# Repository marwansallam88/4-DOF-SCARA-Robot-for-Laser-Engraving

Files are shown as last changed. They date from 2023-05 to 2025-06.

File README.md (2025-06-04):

# 4-DOF SCARA Robot for Laser Engraving
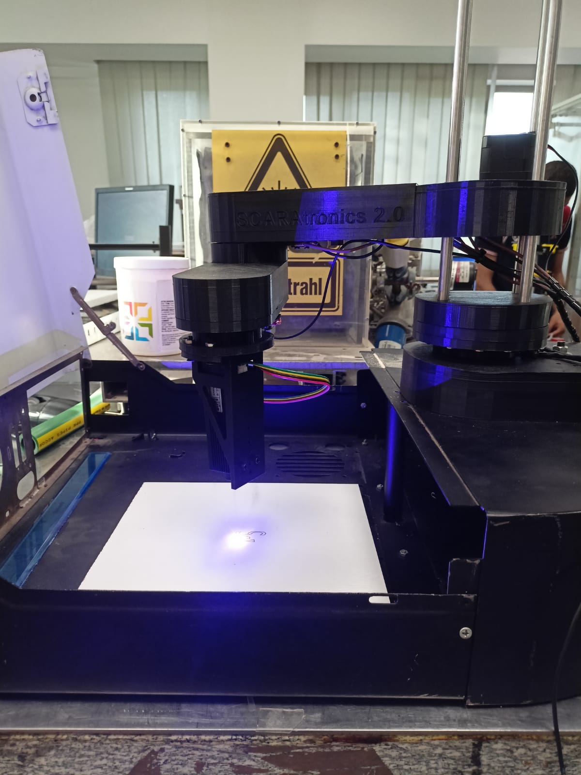
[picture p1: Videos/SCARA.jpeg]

## Overview
This repository contains the design, control, and simulation files for a 4-DOF SCARA robot used for laser engraving. The project includes:
- **Mathematical modeling** (kinematics and dynamics) using MATLAB/Simulink.
- **Control algorithms** implemented via Marlin firmware on an Arduino Mega.
- **3D design files** (SolidWorks) for robot assembly.
- **Experimental results** showcasing laser engraving capabilities.

## Features
- **4 Degrees of Freedom**: Three rotational joints (X-Y plane) and one vertical prismatic joint (Z-axis).
- **Laser Engraving**: Custom end-effector for precise engraving on workpieces.
- **Inverse Kinematics**: Geometric and algebraic solutions for path planning.
- **Open-Source Control**: Marlin firmware configured for SCARA kinematics.
- **Modular Design**: Easily replaceable end-effectors for diverse applications.

## Repository Structure
SCARA-Robot-Laser-Engraving/  
├── SCARA MODEL/ # 3D models and assembly files  
├── Mathmetical Model/ # Forward/inverse kinematics and dynamics  
├── Control/Marlin-2.0.x/ # Marlin configuration and motor test codes  
├── Videos/ # Images and data from engraving tests  
└── Thesis/ # Thesis PDF and supplementary notes  

## Key Components
- **Hardware**:
  - NEMA 17 stepper motors (4x).
  - GT2 belts and pulleys for joint actuation.
  - 12V laser module (PWM-controlled).
  - Limit switches for homing.
- **Software**:
  - MATLAB/Simulink for simulation.
  - Marlin firmware (customized for SCARA).
  - Repetier-Host for G-code execution.
  - Inkscape + LaserTools plugin for G-code generation.

## Setup Instructions
1. **Assembly**:
   - 3D-print parts from `SCARA MODEL`.
   - Assemble belts, pulleys, and motors as per the thesis (Chapter 5).
2. **Electronics**:
   - Connect steppers, limit switches, and laser to Arduino Mega/RAMPS 1.6.
   - Adjust stepper driver currents using `V_ref = I_mot * 8 * R_sense`.
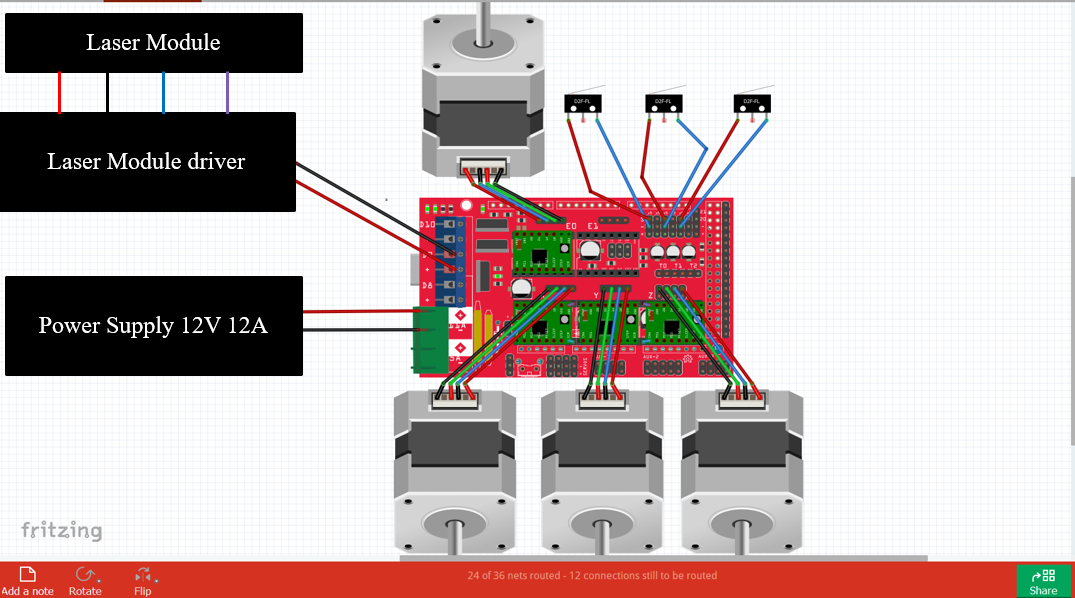
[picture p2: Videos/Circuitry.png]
     
3. **Firmware**:
   - Upload Marlin firmware (`Control/Marlin-2.0.x`) with SCARA-specific settings:
     - Arm lengths: 228mm (Link 1), 136.5mm (Link 2).
     - Steps/unit: 90 (Joint 1), 29.206 (Joint 2), 400 (Z-axis).
4. **Calibration**:
   - Home the robot using limit switches.
   - Focus the laser at ~5cm height (adjust lens rotation).
5. **Operation**:
   - Generate G-code in Inkscape (vector paths → LaserTools plugin).
   - Execute via Repetier-Host.

## Results
- **Simulations**: Validated forward/inverse kinematics and dynamics (see `Mathmetical Model/`).
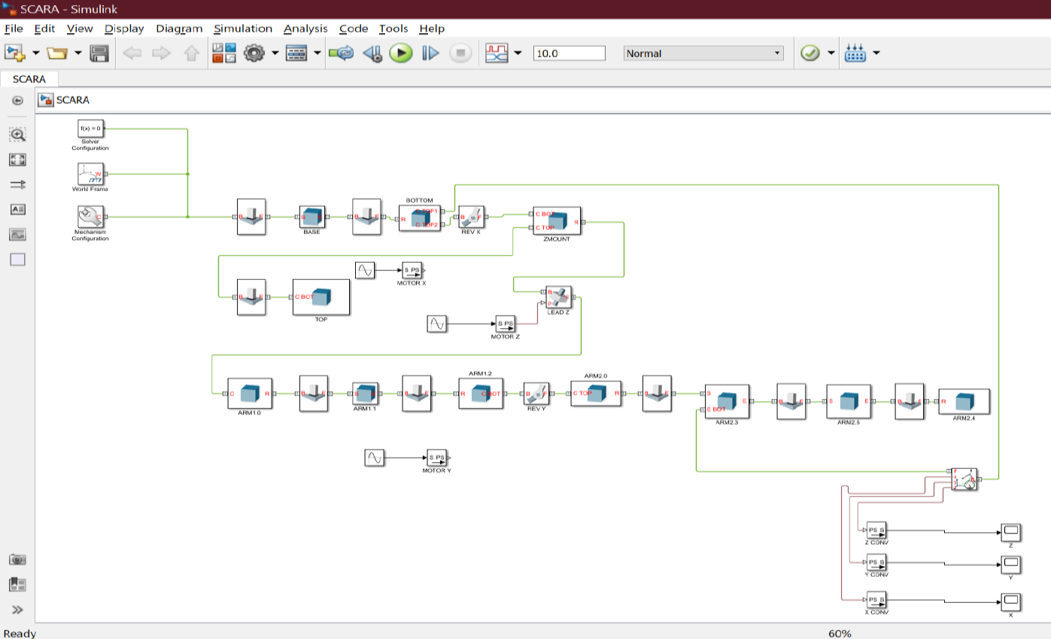
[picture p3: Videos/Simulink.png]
  
- **Engraving Tests**:
  - Contour shapes (e.g., squares, logos).
  - Text engraving (e.g., "GUC 20 YEARS").
  - Infill patterns (e.g., bat shape).
  <p align="center">
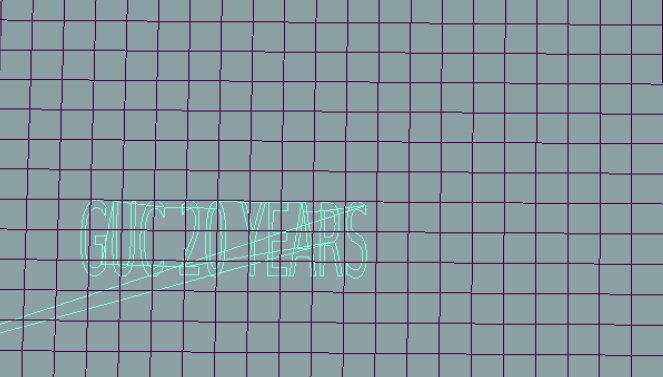
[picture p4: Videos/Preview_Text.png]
  
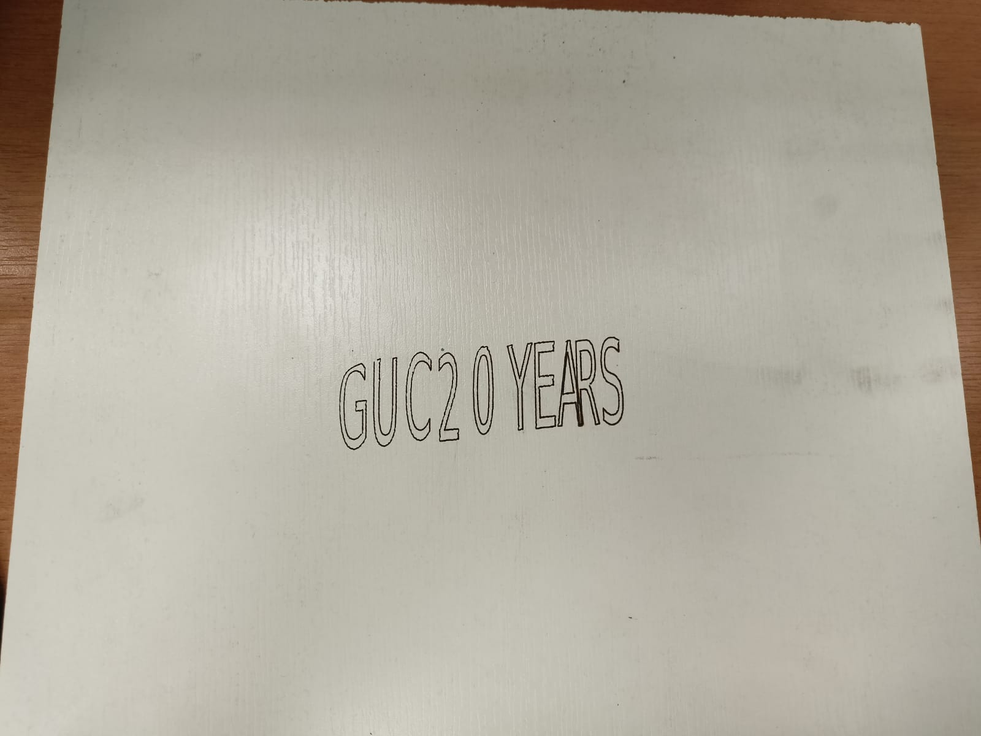
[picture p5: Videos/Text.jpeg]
  
</p>

## Future Work
- Integrate computer vision for real-time adjustments.
- Implement soft grippers for pick-and-place tasks.
- Enhance rigidity to reduce positional errors.

## References
- Thesis: *Four Degrees of Freedom SCARA Robot Used for Laser Engraving* (Marwan Sallam, 2022).
- [Marlin Firmware](https://marlinfw.org/)
- [Inkscape LaserTools](https://github.com/jncordon/lasertools)

## License
Open-source (MIT). Use freely for academic or personal projects.

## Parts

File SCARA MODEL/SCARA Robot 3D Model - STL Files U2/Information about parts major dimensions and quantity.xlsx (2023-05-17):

Part Name | Quantity | Length(mm) | Width(mm) | Height(mm) | Extra Info |  | Colour
Arduino Mega Case | 1 | 120 | 85 | 45 |  |  | Black
Arduino Mega Case p2 | 1 | 120 | 80 | 40 |  |  | Black
Arm 1 | 1 | 205 | 80 | 45 | Will carrry heavy load so should be strong but lightweight |  | Black
Arm 1 Cover | 1 | 205 | 80 | 5 | Will carrry heavy load so should be strong but lightweight |  | Black
Base | 1 | 215 | 140 | 45 | This is the base of porject so should be dense |  | Black
Base Cover | 1 | 120 | 120 | 25 | This is the base of porject so should be dense |  | Black
Arm 2 | 1 | 225 | 80 | 35 | Will carrry heavy load so should be strong but lightweight |  | Black
Arm 2 cover | 1 | 225 | 80 | 10 | Will carrry heavy load so should be strong but lightweight |  | Black
Arm 1 motor pulley - 63 Teeth - D40mm | 1 | 40 | 40 | 15 | Should withstand friction and force |  | Black
Arm 1 Pulley Middle - 44 Teeth - 99 Teeth - D31mm - D66mm | 1 | 66 | 66 | 20 | Should withstand friction and force |  | Black
Arm 2 Motor Pulley - 68 Teeth - D46mm | 1 | 46 | 46 | 15 | Should withstand friction and force |  | Black
Base Motor Pulley - 20 Teeth - D14.5mm | 1 | 14.5 | 14.5 | 15 | Should withstand friction and force |  | Black
Base Pulley - 44 Teeth - 81 Teeth - D31mm - D52mm | 1 | 52 | 52 | 20 | Should withstand friction and force |  | Black
Tensioner Pulley | 5 | 15 | 15 | 15 | Should withstand friction and force |  | Black
GT2 Pulley -110 teeth- J1 | 1 | 72 | 72 | 25 | Should withstand friction and force |  | Black
GT2 Pulley -92 teeth- J2 | 1 | 60.5 | 60.5 | 20 | Should withstand friction and force |  | Black
GT2 Pulley -90 teeth- J3 | 1 | 59 | 59 | 25 | Should withstand friction and force |  | Black
Smooth rod clamp | 8 | 40 | 15 | 30 |  |  | Black
Z-axis top plate | 1 | 120 | 120 | 25 |  |  | Black
Z-axis Mount Platform | 1 | 125 | 120 | 45 |  |  | Black
Z-axis Bottom Plate | 1 | 120 | 120 | 10 |  |  | Black
Top cover | 1 | 120 | 120 | 25 |  |  | Black
J3 Coupler | 1 | 80 | 80 | 25 |  |  | Black
J2 Coupler | 1 | 80 | 80 | 25 |  |  | Black
J1 Coupler | 1 | 120 | 120 | 30 |  |  | Black
Laser Module Holder | 1 | 80 | 45 | 115 |  |  | Black
 | New |  |  |  | Old
using teeth | Reduction Ratio
First Joint | 10.125 | 10.125 | 90.00000000 |  | 20 | 177.7777778
Second Joint | 3.285714286 | 3.286 | 29.20634921 |  | 16 | 142.2222222
Third Joint | 1.323529412 | 1.324 | 11.76470588 |  | 4.5 | 40
 |  |  |  |  |  |  | 0
using diameters
First Joint | 9.999524881 | 10 | 88.88466561
Second Joint | 3.573844215 | 3.574 | 31.76750413
Third Joint | 1.328528779 | 1.329 | 11.80914470

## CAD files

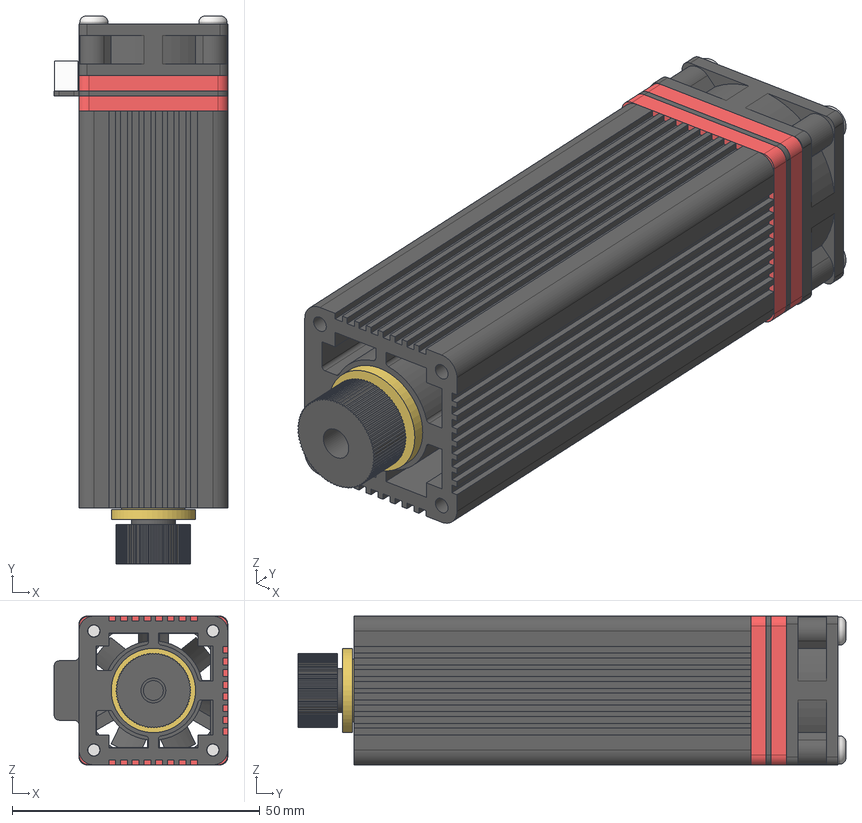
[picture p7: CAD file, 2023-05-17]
SCARA MODEL/SCARA Robot 3D Model - STL Files U2/neje-n30820-laser-module-20w-1.snapshot.1/A-NEJE_N30820_assembled.stp
35.0 x 110.5 x 30.0 mm
NEJE_N30820_Aluminiumbody
NEJE_N30820_Lens
NEJE_N30820_SLA-Spacer(red) x 2
NEJE_N30820_PCB
ANSI B18.3.4M - M3 x 0.5 x 30 x 4

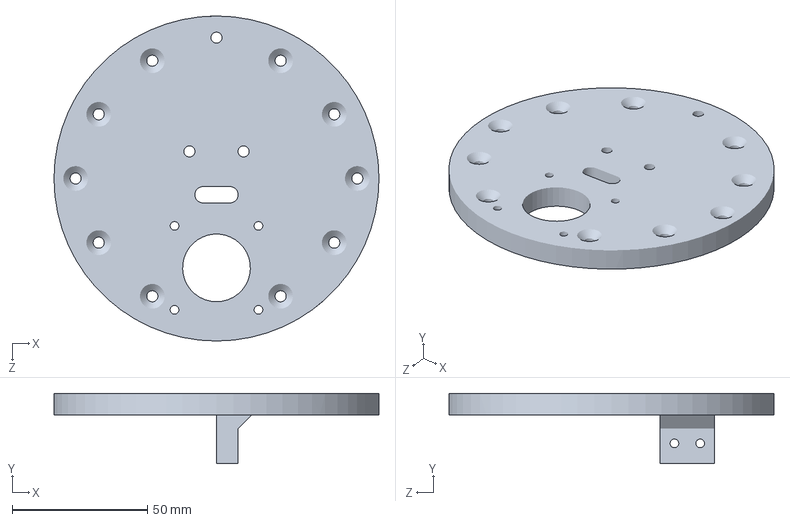
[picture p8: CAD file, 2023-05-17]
SCARA MODEL/SCARA Robot 3D Model - STL Files U2/Z-axis Top Plate.SLDPRT
120.0 x 26.0 x 120.0 mm

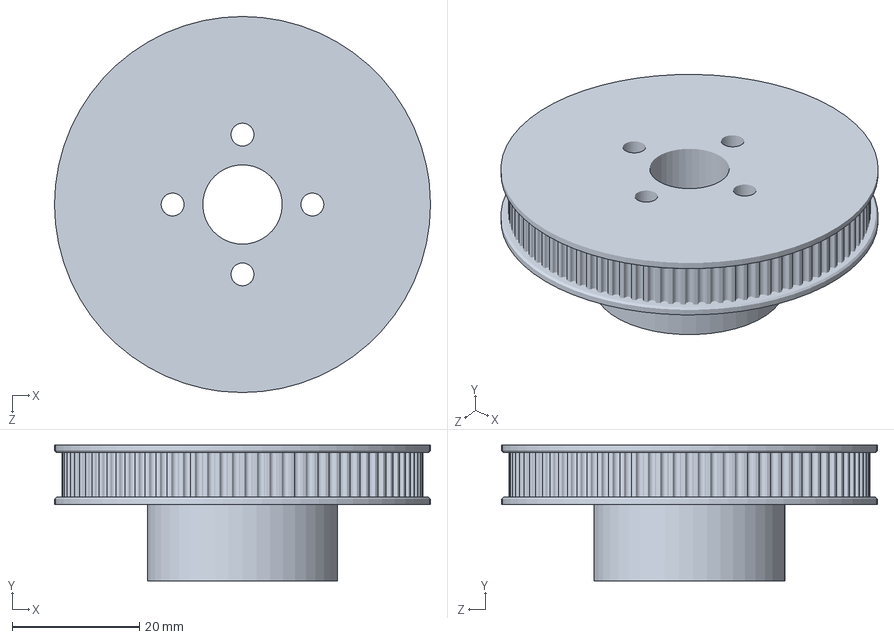
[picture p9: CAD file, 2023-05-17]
SCARA MODEL/SCARA Robot 3D Model - STL Files U2/GT2 Pulley - 90 teeth - J3 - D59mm.SLDPRT
59.2 x 21.4 x 59.2 mm

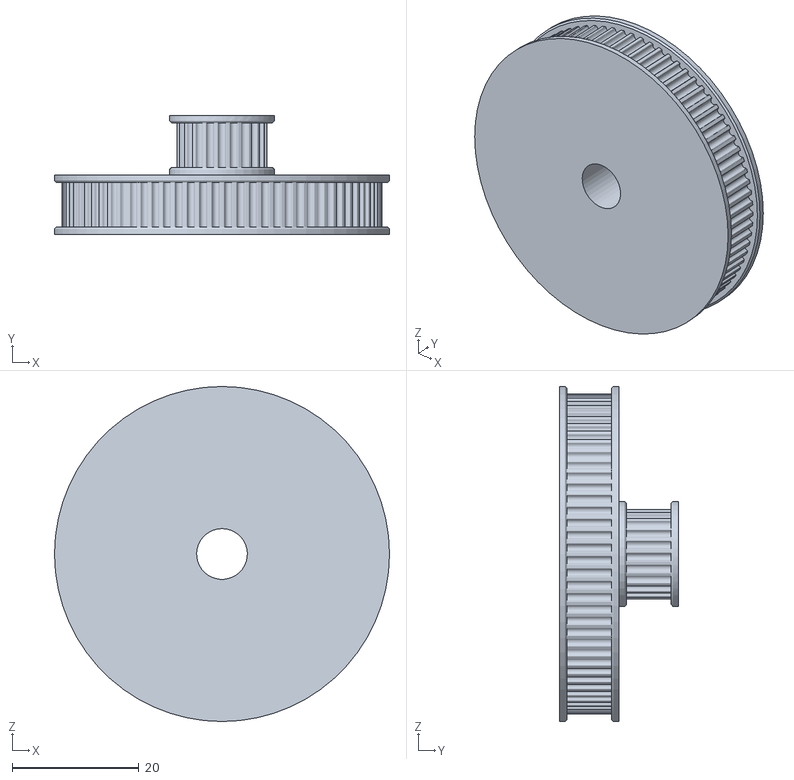
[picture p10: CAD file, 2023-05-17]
SCARA MODEL/SCARA Robot 3D Model - STL Files U2/GT2 Pulley - 23 - 80 teeth.STL
52.8 x 18.8 x 52.8

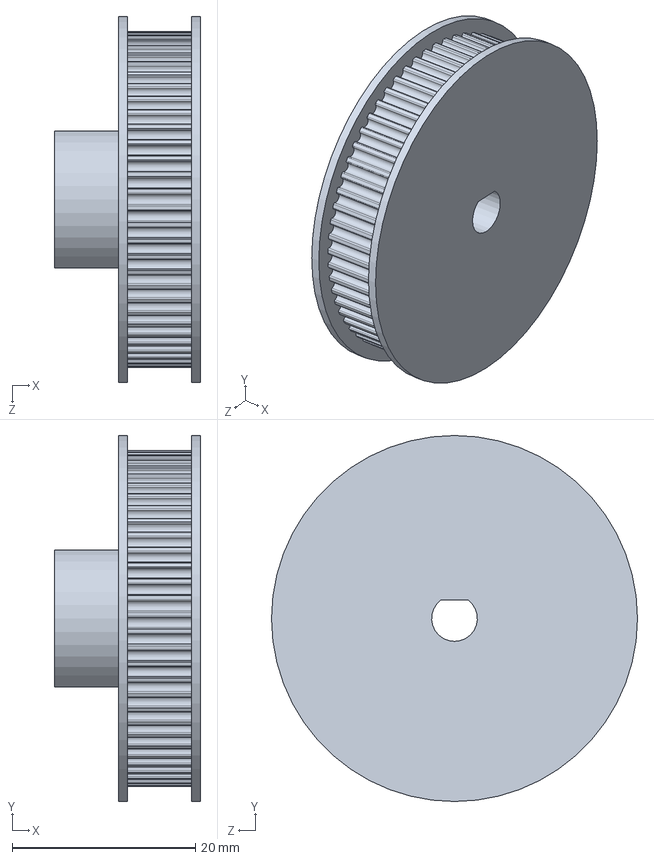
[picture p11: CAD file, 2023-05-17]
SCARA MODEL/SCARA Robot 3D Model - STL Files U2/Arm 1 motor pulley - 63 Teeth - D40mm.SLDPRT
16.0 x 40.0 x 40.0 mm

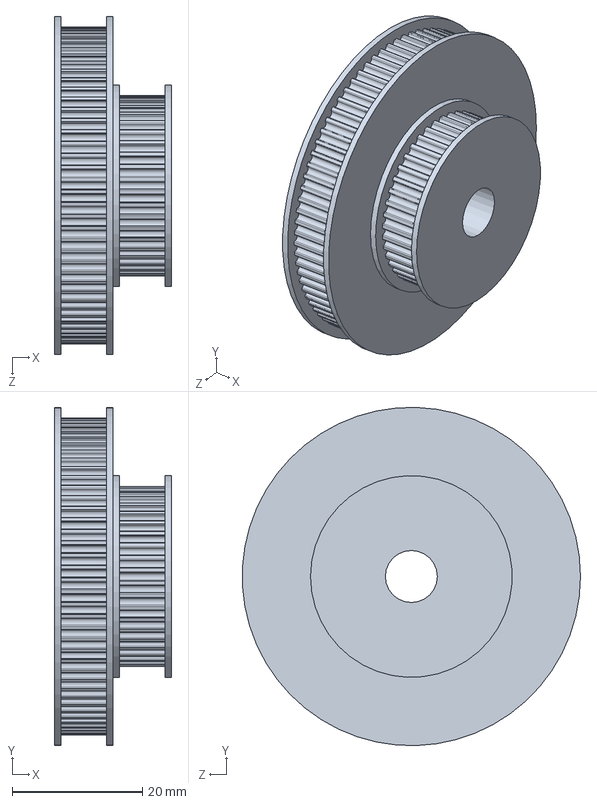
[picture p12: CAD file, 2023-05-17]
SCARA MODEL/SCARA Robot 3D Model - STL Files U2/Base Pulley - 44 Teeth - 81 Teeth - D31mm - D52mm.SLDPRT
18.0 x 52.0 x 52.0 mm

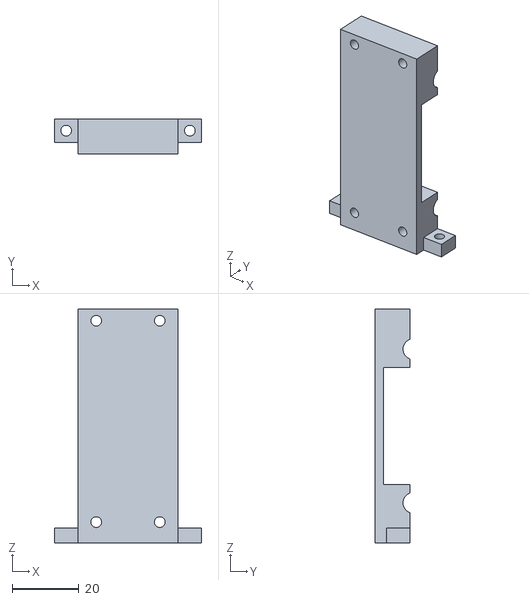
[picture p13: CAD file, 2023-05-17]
SCARA MODEL/SCARA Robot 3D Model - STL Files U2/Gripper Cover.STL
44.0 x 10.5 x 70.0

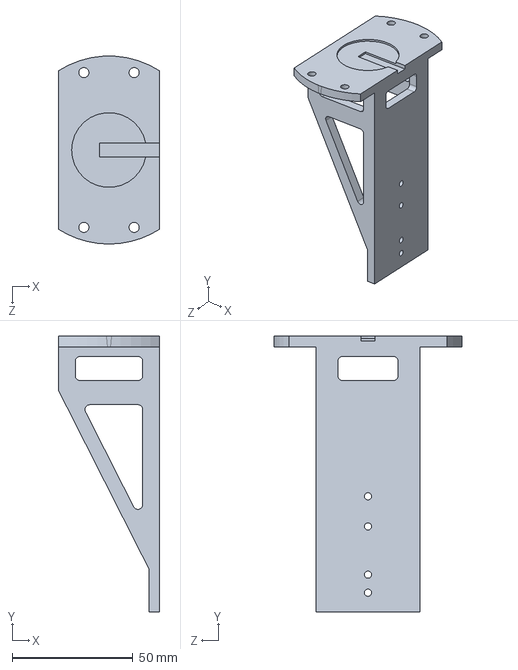
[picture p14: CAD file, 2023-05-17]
SCARA MODEL/SCARA Robot 3D Model - STL Files U2/Laser module holder.SLDPRT
42.0 x 114.5 x 78.0 mm

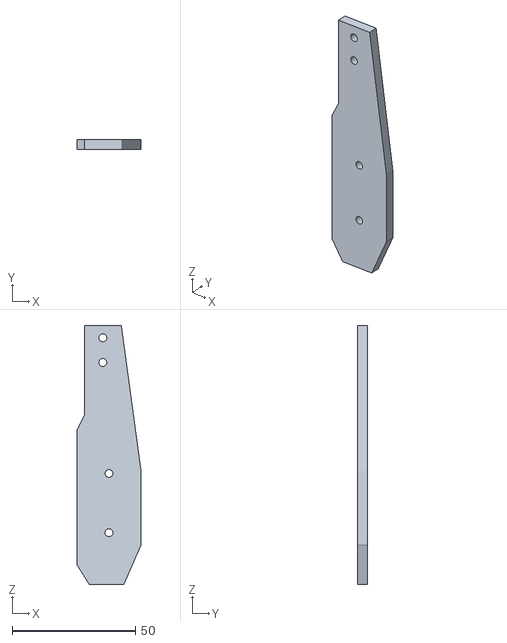
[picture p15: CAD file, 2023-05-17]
SCARA MODEL/SCARA Robot 3D Model - STL Files U2/Gripper Hand Right.STL
26.0 x 4.00 x 105.0

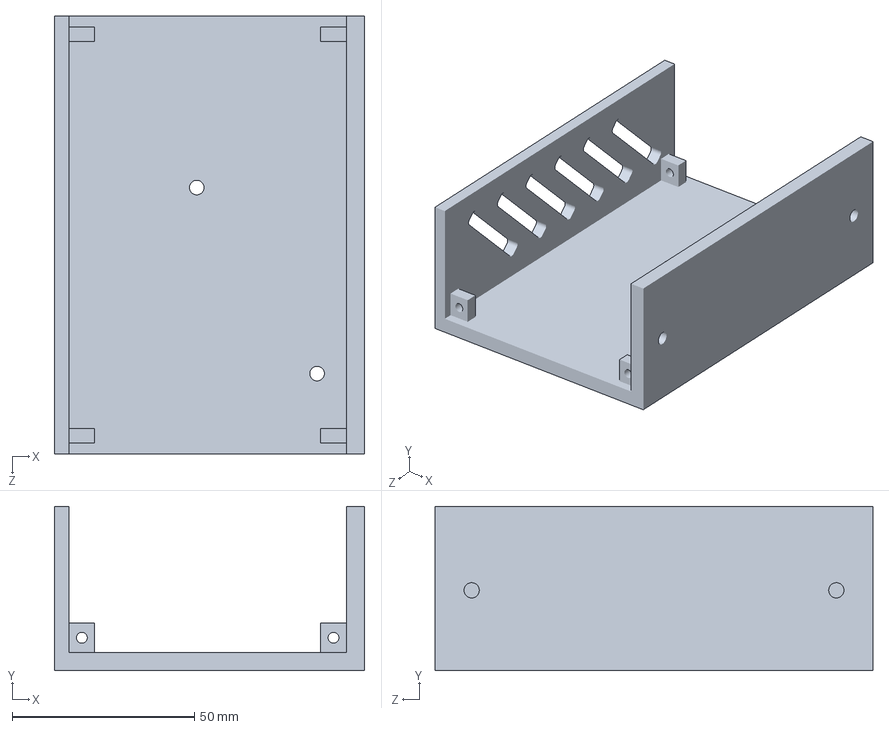
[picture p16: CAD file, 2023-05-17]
SCARA MODEL/SCARA Robot 3D Model - STL Files U2/Arduino Mega case.SLDPRT
85.0 x 45.0 x 120.0 mm

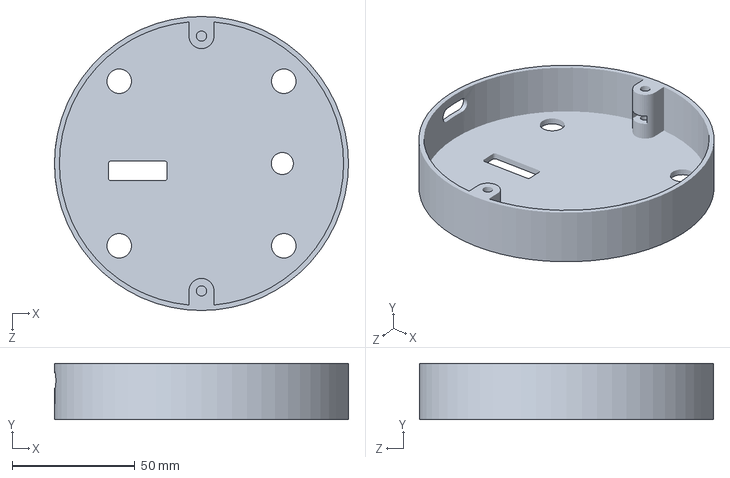
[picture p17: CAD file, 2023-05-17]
SCARA MODEL/SCARA Robot 3D Model - STL Files U2/Top cover.SLDPRT
120.0 x 23.0 x 120.0 mm

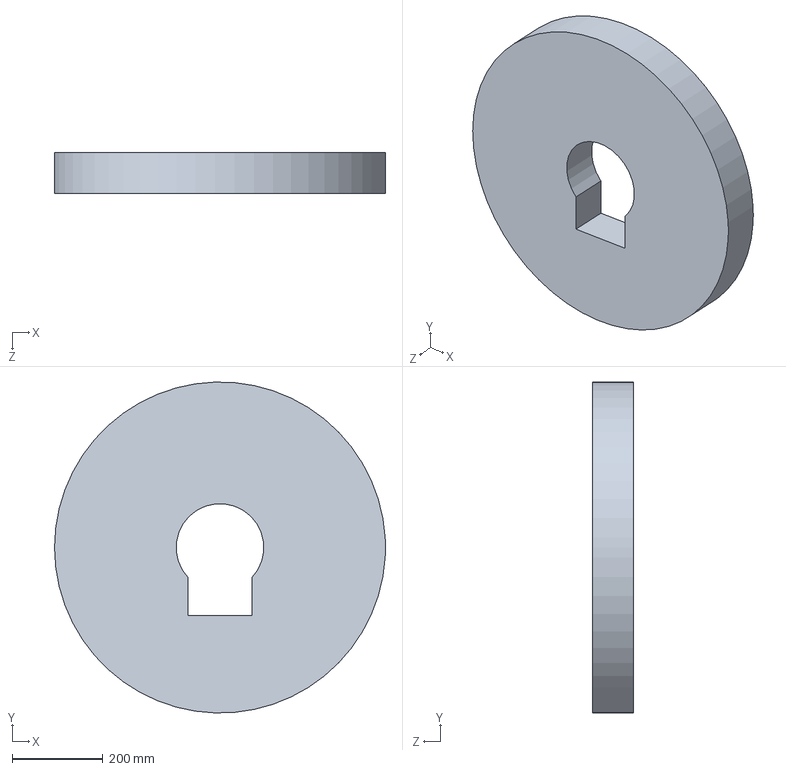
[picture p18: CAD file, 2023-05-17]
SCARA MODEL/SCARA Robot 3D Model - STL Files U2/workspace.SLDPRT
729.0 x 728.7 x 91.0 mm

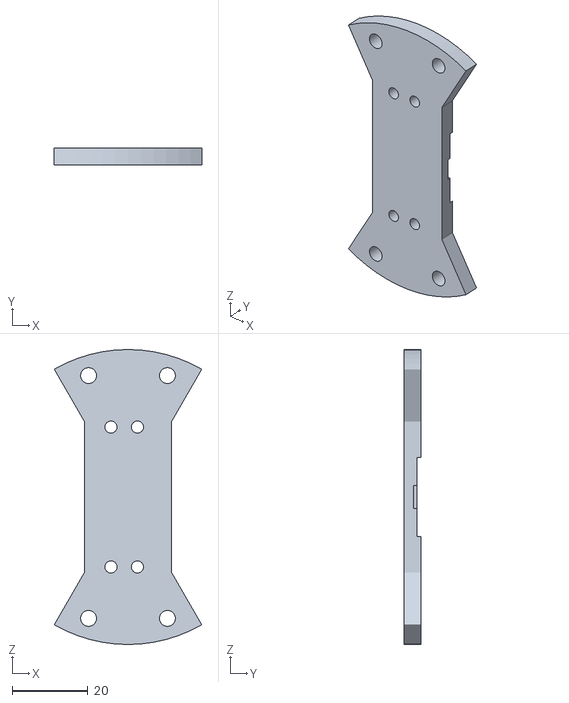
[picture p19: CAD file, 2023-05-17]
SCARA MODEL/SCARA Robot 3D Model - STL Files U2/Gripper to J3 connector.STL
39.0 x 4.50 x 78.0

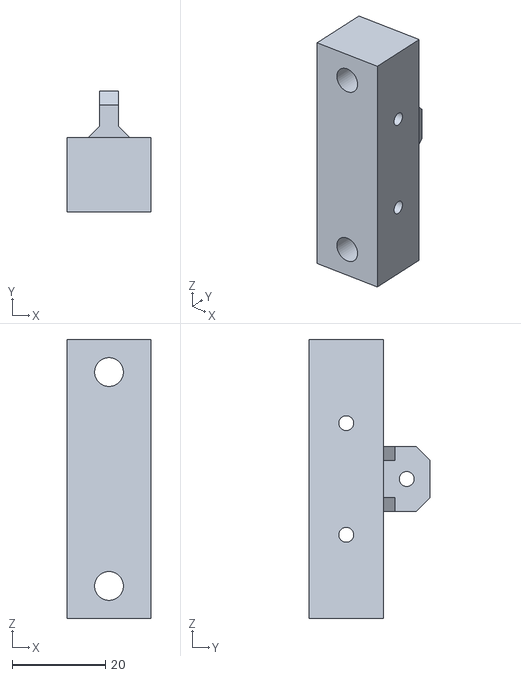
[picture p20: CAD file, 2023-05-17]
SCARA MODEL/SCARA Robot 3D Model - STL Files U2/Gripper Mechanism Slider.STL
18.0 x 26.0 x 60.0

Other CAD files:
SCARA MODEL/SCARA Robot 3D Model - STL Files U2/SCARA OFFSET.SLDPRT
SCARA MODEL/SCARA Robot 3D Model - STL Files U2/J3 Coupler.SLDPRT
SCARA MODEL/SCARA Robot 3D Model - STL Files U2/Smooth Rod Clamp.SLDPRT
SCARA MODEL/SCARA Robot 3D Model - STL Files U2/GT2 Pulley - 110 teeth - J1.STL
SCARA MODEL/SCARA Robot 3D Model - STL Files U2/Arduino Mega case p2.SLDPRT
SCARA MODEL/SCARA Robot 3D Model - STL Files U2/Arduino Mega case p2.STL
SCARA MODEL/SCARA Robot 3D Model - STL Files U2/Arduino Mega case.STL
SCARA MODEL/SCARA Robot 3D Model - STL Files U2/Arduino UNO case p1.STL
SCARA MODEL/SCARA Robot 3D Model - STL Files U2/Arduino UNO case p2.STL
SCARA MODEL/SCARA Robot 3D Model - STL Files U2/Arm 1 Cover.SLDPRT
SCARA MODEL/SCARA Robot 3D Model - STL Files U2/Arm 1 Cover.STL
SCARA MODEL/SCARA Robot 3D Model - STL Files U2/Arm 1 Pulley Middle - 44 Teeth - 99 Teeth - D31mm - D66mm.SLDPRT
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

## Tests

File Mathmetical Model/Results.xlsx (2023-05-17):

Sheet: Kine S Y
Time | Y
0 | 0
0.000430977095 | 5.4086534e-06
0.0008619541901 | 3.539515969e-05
0.001358518811 | 0.0001111131155
0.001981448586 | 0.000265702842
0.002742152024 | 0.0005248783451
0.003680813786 | 0.0009137942667
0.004877582879 | 0.001467886721
0.006560880035 | 0.002291062328
0.009042260391 | 0.003528914422
0.01148760951 | 0.004753101366
0.01454943029 | 0.006286573817
0.01791619063 | 0.007972568813
0.02113159993 | 0.009582567961
0.02416520633 | 0.01110131924
0.02737275602 | 0.0127067233
0.0314853292 | 0.01476467813
0.03372316461 | 0.01588369875
0.03596100003 | 0.01700259135
0.03910755649 | 0.0185754654
0.04258274593 | 0.02031205186
0.0455207786 | 0.0217792712
0.04799304481 | 0.023013124
0.05060936536 | 0.02431852073
0.05368082652 | 0.02585037017
0.05682579027 | 0.02741802755
0.05964560509 | 0.02882260458
0.06226516506 | 0.03012662994
0.06503041043 | 0.0315024629
0.06800560244 | 0.03298185339
0.07093906743 | 0.03443944841
0.07369502907 | 0.03580778309
0.07640166269 | 0.03715067099
0.07921018647 | 0.03854312285
0.08208178451 | 0.03996573548
0.08489327589 | 0.04135739015
0.08763067439 | 0.04271120838
0.09037467029 | 0.04406714455
0.09316348712 | 0.04544402519
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

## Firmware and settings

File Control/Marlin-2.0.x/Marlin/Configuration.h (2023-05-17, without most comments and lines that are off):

#pragma once
#define CONFIG_EXAMPLES_DIR "SCARA/MP_SCARA"
#define CONFIGURATION_H_VERSION 02000900
#define MP_SCARA
  #define SCARA_SEGMENTS_PER_SECOND 100
  #define SCARA_LINKAGE_1  228    // (mm)
  #define SCARA_LINKAGE_2 136.5    // (mm)
  #define SCARA_OFFSET_X    240       // (mm)
  #define SCARA_OFFSET_Y    -80       // (mm)
    #define SCARA_OFFSET_THETA1  0 // degrees
    #define SCARA_OFFSET_THETA2 0 // degrees
#define STRING_CONFIG_H_AUTHOR "(none, default config)" // Who made the changes.
#define SHOW_BOOTSCREEN
#define SERIAL_PORT 0
#define BAUDRATE 115200
  #define MOTHERBOARD BOARD_RAMPS_14_EFB
#define CUSTOM_MACHINE_NAME "SCARA"
#if LINEAR_AXES >= 4
  #define AXIS4_NAME 'A' // :['A', 'B', 'C', 'U', 'V', 'W']
#endif
#if LINEAR_AXES >= 5
  #define AXIS5_NAME 'B' // :['A', 'B', 'C', 'U', 'V', 'W']
#endif
#if LINEAR_AXES >= 6
  #define AXIS6_NAME 'C' // :['A', 'B', 'C', 'U', 'V', 'W']
#endif
#define EXTRUDERS 1
#define DEFAULT_NOMINAL_FILAMENT_DIA 1.75
#define TEMP_SENSOR_0 1
#define TEMP_SENSOR_1 0
#define TEMP_SENSOR_2 0
#define TEMP_SENSOR_3 0
#define TEMP_SENSOR_4 0
#define TEMP_SENSOR_5 0
#define TEMP_SENSOR_6 0
#define TEMP_SENSOR_7 0
#define TEMP_SENSOR_BED 1
#define TEMP_SENSOR_PROBE 0
#define TEMP_SENSOR_CHAMBER 0
#define TEMP_SENSOR_COOLER 0
#define TEMP_SENSOR_REDUNDANT 0
#define DUMMY_THERMISTOR_998_VALUE  25
#define DUMMY_THERMISTOR_999_VALUE 100
#define TEMP_RESIDENCY_TIME          3  // (seconds) Time to wait for hotend to "settle" in M109
#define TEMP_HYSTERESIS              2  // (°C) Temperature proximity considered "close enough" to the target
#define TEMP_WINDOW                  1  // (°C) Temperature proximity for the "temperature reached" timer
#define TEMP_BED_RESIDENCY_TIME      0  // (seconds) Time to wait for bed to "settle" in M190
#define TEMP_BED_WINDOW              1  // (°C) Temperature proximity for the "temperature reached" timer
#define TEMP_BED_HYSTERESIS          3  // (°C) Temperature proximity considered "close enough" to the target
#define TEMP_CHAMBER_RESIDENCY_TIME 10  // (seconds) Time to wait for chamber to "settle" in M191
#define TEMP_CHAMBER_WINDOW          1  // (°C) Temperature proximity for the "temperature reached" timer
#define TEMP_CHAMBER_HYSTERESIS      3  // (°C) Temperature proximity considered "close enough" to the target
#if TEMP_SENSOR_REDUNDANT
  #define TEMP_SENSOR_REDUNDANT_SOURCE     1  // The sensor that will provide the redundant reading.
  #define TEMP_SENSOR_REDUNDANT_TARGET     0  // The sensor that we are providing a redundant reading for.
  #define TEMP_SENSOR_REDUNDANT_MAX_DIFF  10  // (°C) Temperature difference that will trigger a print abort.
#endif
#define HEATER_0_MINTEMP   5
#define HEATER_1_MINTEMP   5
#define HEATER_2_MINTEMP   5
#define HEATER_3_MINTEMP   5
#define HEATER_4_MINTEMP   5
#define HEATER_5_MINTEMP   5
#define HEATER_6_MINTEMP   5
#define HEATER_7_MINTEMP   5
#define BED_MINTEMP        5
#define CHAMBER_MINTEMP    5
#define HEATER_0_MAXTEMP 275
#define HEATER_1_MAXTEMP 275
#define HEATER_2_MAXTEMP 275
#define HEATER_3_MAXTEMP 275
#define HEATER_4_MAXTEMP 275
#define HEATER_5_MAXTEMP 275
#define HEATER_6_MAXTEMP 275
#define HEATER_7_MAXTEMP 275
#define BED_MAXTEMP      150
#define CHAMBER_MAXTEMP  60
#define HOTEND_OVERSHOOT 15   // (°C) Forbid temperatures over MAXTEMP - OVERSHOOT
#define BED_OVERSHOOT    10   // (°C) Forbid temperatures over MAXTEMP - OVERSHOOT
#define COOLER_OVERSHOOT  2   // (°C) Forbid temperatures closer than OVERSHOOT
#define PIDTEMP
#define BANG_MAX 255     // Limits current to nozzle while in bang-bang mode; 255=full current
#define PID_MAX BANG_MAX // Limits current to nozzle while PID is active (see PID_FUNCTIONAL_RANGE below); 255=full current
#define PID_K1 0.95      // Smoothing factor within any PID loop
    #define DEFAULT_Kp  24.50
    #define DEFAULT_Ki   1.72
    #define DEFAULT_Kd  87.73
#define PIDTEMPBED
#define MAX_BED_POWER 255 // limits duty cycle to bed; 255=full current
  #define DEFAULT_bedKp 630.14
  #define DEFAULT_bedKi 121.71
  #define DEFAULT_bedKd 815.64
#define MAX_CHAMBER_POWER 255 // limits duty cycle to chamber heater; 255=full current
  #define PID_FUNCTIONAL_RANGE 20 // If the temperature difference between the target temperature and the actual temperature
#define PREVENT_COLD_EXTRUSION
#define EXTRUDE_MINTEMP 170
#define PREVENT_LENGTHY_EXTRUDE
#define EXTRUDE_MAXLENGTH 200
#define THERMAL_PROTECTION_HOTENDS // Enable thermal protection for all extruders
#define THERMAL_PROTECTION_BED     // Enable thermal protection for the heated bed
#define THERMAL_PROTECTION_CHAMBER // Enable thermal protection for the heated chamber
#define THERMAL_PROTECTION_COOLER  // Enable thermal protection for the laser cooling
#define USE_XMIN_PLUG
#define USE_YMIN_PLUG
#define USE_ZMIN_PLUG
#define ENDSTOPPULLUPS
#define X_MIN_ENDSTOP_INVERTING false // Set to true to invert the logic of the endstop.
#define Y_MIN_ENDSTOP_INVERTING false // Set to true to invert the logic of the endstop.
#define Z_MIN_ENDSTOP_INVERTING false // Set to true to invert the logic of the endstop.
#define I_MIN_ENDSTOP_INVERTING false // Set to true to invert the logic of the endstop.
#define J_MIN_ENDSTOP_INVERTING false // Set to true to invert the logic of the endstop.
#define K_MIN_ENDSTOP_INVERTING false // Set to true to invert the logic of the endstop.
#define X_MAX_ENDSTOP_INVERTING false // Set to true to invert the logic of the endstop.
#define Y_MAX_ENDSTOP_INVERTING false // Set to true to invert the logic of the endstop.
#define Z_MAX_ENDSTOP_INVERTING false // Set to true to invert the logic of the endstop.
#define I_MAX_ENDSTOP_INVERTING false // Set to true to invert the logic of the endstop.
#define J_MAX_ENDSTOP_INVERTING false // Set to true to invert the logic of the endstop.
#define K_MAX_ENDSTOP_INVERTING false // Set to true to invert the logic of the endstop.
#define Z_MIN_PROBE_ENDSTOP_INVERTING false // Set to true to invert the logic of the probe.
#define DEFAULT_AXIS_STEPS_PER_UNIT   { 73.77777778, 28.44444444, 400, 11.55555556 }
#define DEFAULT_MAX_FEEDRATE          { 1000, 1000, 2.5, 25 }
#define DEFAULT_MAX_ACCELERATION      { 1000, 1000, 10, 20000 }
#define DEFAULT_ACCELERATION          1000    // X, Y, Z and E acceleration for printing moves
#define DEFAULT_RETRACT_ACCELERATION  1000    // E acceleration for retracts
#define DEFAULT_TRAVEL_ACCELERATION   1000    // X, Y, Z acceleration for travel (non printing) moves
#define CLASSIC_JERK
  #define DEFAULT_XJERK  5.0
  #define DEFAULT_YJERK  5.0
  #define DEFAULT_ZJERK  0.3
#define DEFAULT_EJERK    3.0  // May be used by Linear Advance
#define NOZZLE_TO_PROBE_OFFSET { -25, -29, -12.35 }
#define PROBING_MARGIN 10
#define XY_PROBE_FEEDRATE (133*60)
#define Z_PROBE_FEEDRATE_FAST (4*60)
#define Z_PROBE_FEEDRATE_SLOW (Z_PROBE_FEEDRATE_FAST / 2)
#define Z_CLEARANCE_DEPLOY_PROBE   15 // Z Clearance for Deploy/Stow
#define Z_CLEARANCE_BETWEEN_PROBES  5 // Z Clearance between probe points
#define Z_CLEARANCE_MULTI_PROBE     5 // Z Clearance between multiple probes
#define Z_PROBE_LOW_POINT          -2 // Farthest distance below the trigger-point to go before stopping
#define Z_PROBE_OFFSET_RANGE_MIN -20
#define Z_PROBE_OFFSET_RANGE_MAX 20
#define X_ENABLE_ON 0
#define Y_ENABLE_ON 0
#define Z_ENABLE_ON 0
#define E_ENABLE_ON 0 // For all extruders
#define DISABLE_X false
#define DISABLE_Y false
#define DISABLE_Z false
#define DISABLE_E false             // Disable the extruder when not stepping
#define DISABLE_INACTIVE_EXTRUDER   // Keep only the active extruder enabled
#define INVERT_X_DIR false
#define INVERT_Y_DIR false
#define INVERT_Z_DIR false
#define INVERT_E0_DIR false
#define INVERT_E1_DIR false
#define INVERT_E2_DIR false
#define INVERT_E3_DIR false
#define INVERT_E4_DIR false
#define INVERT_E5_DIR false
#define INVERT_E6_DIR false
#define INVERT_E7_DIR false
#define X_HOME_DIR -1
#define Y_HOME_DIR -1
#define Z_HOME_DIR -1
#define X_BED_SIZE 480
#define Y_BED_SIZE 400
#define X_MIN_POS 0
#define Y_MIN_POS 0
#define Z_MIN_POS 0
#define X_MAX_POS X_BED_SIZE
#define Y_MAX_POS X_BED_SIZE
#define Z_MAX_POS 100
#define MAX_SOFTWARE_ENDSTOPS
  #define MAX_SOFTWARE_ENDSTOP_X
  #define MAX_SOFTWARE_ENDSTOP_Y
  #define MAX_SOFTWARE_ENDSTOP_Z
  #define MAX_SOFTWARE_ENDSTOP_I
  #define MAX_SOFTWARE_ENDSTOP_J
  #define MAX_SOFTWARE_ENDSTOP_K
#define MANUAL_X_HOME_POS 240
#define MANUAL_Y_HOME_POS -444.50
#define HOMING_FEEDRATE_MM_M { (80*60), (80*60), (4*60) }
#define EEPROM_CHITCHAT       // Give feedback on EEPROM commands. Disable to save PROGMEM.
#define EEPROM_BOOT_SILENT    // Keep M503 quiet and only give errors during first load
#define HOST_KEEPALIVE_FEATURE        // Disable this if your host doesn't like keepalive messages
#define DEFAULT_KEEPALIVE_INTERVAL 2  // Number of seconds between "busy" messages. Set with M113.
#define BUSY_WHILE_HEATING            // Some hosts require "busy" messages even during heating
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

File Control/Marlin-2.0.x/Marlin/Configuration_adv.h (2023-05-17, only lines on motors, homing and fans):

#define E0_AUTO_FAN_PIN -1
#define E1_AUTO_FAN_PIN -1
#define E2_AUTO_FAN_PIN -1
#define E3_AUTO_FAN_PIN -1
#define E4_AUTO_FAN_PIN -1
#define E5_AUTO_FAN_PIN -1
#define E6_AUTO_FAN_PIN -1
#define E7_AUTO_FAN_PIN -1
#define CHAMBER_AUTO_FAN_PIN -1
#define COOLER_AUTO_FAN_PIN -1
#define COOLER_FAN_PIN -1
#define HOMING_BUMP_MM      { 2, 2, 2 }       // (mm) Backoff from endstops after first bump
#define HOMING_BUMP_DIVISOR { 2, 2, 4 }       // Re-Bump Speed Divisor (Divides the Homing Feedrate)
#define QUICK_HOME                          // If G28 contains XY do a diagonal move first
#define MICROSTEP_MODES { 16, 16, 16, 16, 16, 16 } // [1,2,4,8,16]

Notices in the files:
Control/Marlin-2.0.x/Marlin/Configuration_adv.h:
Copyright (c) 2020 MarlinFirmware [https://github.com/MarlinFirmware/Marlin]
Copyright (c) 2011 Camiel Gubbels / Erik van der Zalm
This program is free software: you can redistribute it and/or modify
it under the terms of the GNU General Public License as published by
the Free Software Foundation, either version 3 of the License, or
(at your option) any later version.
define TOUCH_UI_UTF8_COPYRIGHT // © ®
